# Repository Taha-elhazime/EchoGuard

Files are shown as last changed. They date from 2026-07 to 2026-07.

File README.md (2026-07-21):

# EchoGuard

EchoGuard is a security system that is meant to be more efficient than conventional cameras. The main part is a camera turret which is ceiling mounted and uses microphones in order to detect suspicious activity and lock on to it. It also uses a wall mounted ultrasonic sensor to detect anyone who walks past a certain line using bluetooth to transmit the data. Assembled demmo 
Demo video: demo

## What is included

This project includes the Cad files for the ultrasonic wall sensor and the turret demo as it is not ceiling mounted, along with the 3mf files in order to print them.
It also includes the codes to use the turret "main_v2.py" is the stable version which tracks the person's face using mediapipe, calculates the bearing of when the face was last seen and the offset from the center (dy and dx) and sends it to the arduino through serial communication. "main_v3" is an experimental version which does not work properly, where I tried to implement ROI in order to increase the speed at which mediapipe analyzed the images by reducing the load. The codes to upload to the microcontrollers are also included.
Before 3d printing the whole thing, I included 3mf files in order to test the snap fit of the ultrasonic sensor "snap_fit_test", along with "bearing_test" as the size of the bearings varies and the project uses bearings for the rotating base.
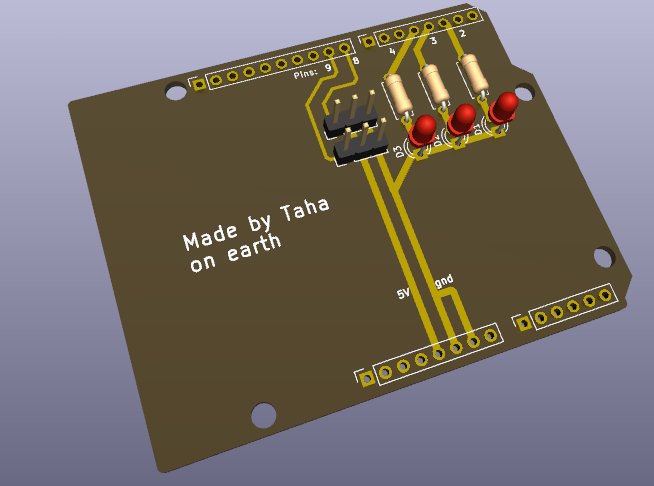
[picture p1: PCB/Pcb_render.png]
PCB
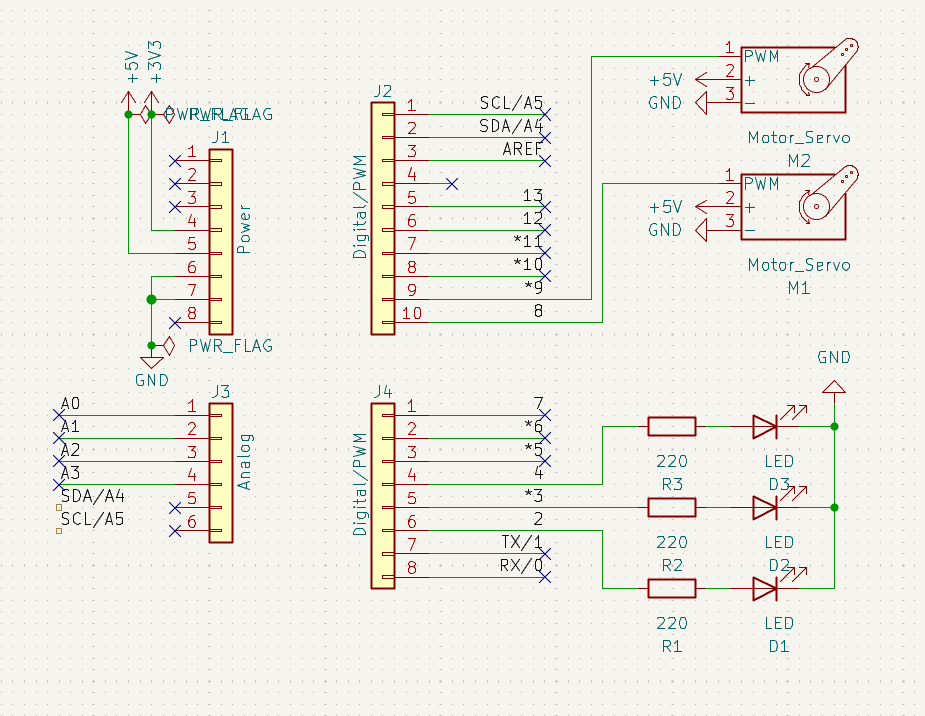
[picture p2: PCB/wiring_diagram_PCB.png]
Wiring_diagram
It also includes a simple pcb that would replace the breadboard and messy jumper wires  

## How to recreate the project

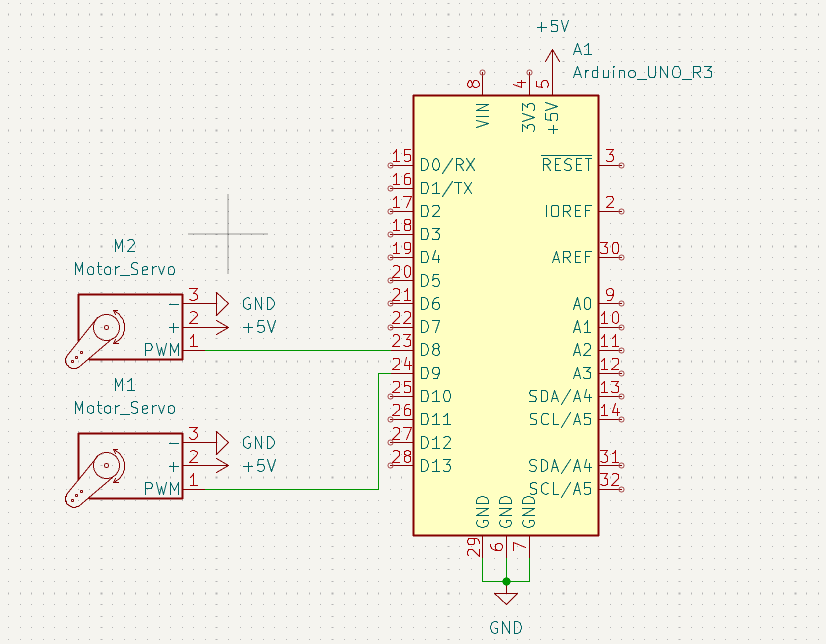
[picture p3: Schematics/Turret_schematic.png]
Turret schematic
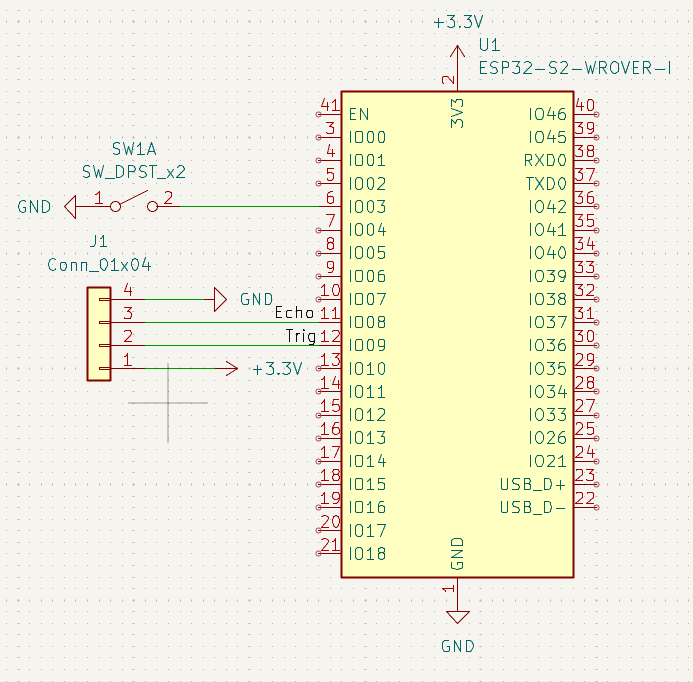
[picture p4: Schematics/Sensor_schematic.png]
Sensor schematic
The circuits are quite simple but here are schematics nontheless  

1. Use Arduino IDE in order to upload the code "EchoGaurd" for the arduino and note down the COM port used.

2. Use your code editor to update the port number in line the 8th line 
arduino = serial.Serial("COM3", 115200) change the number 3 with your port. 

3. Install the libraries mediapipe, opencv, pyserial, and numpy by running these comands in the terminal
```sh
pip install opencv-python
pip install mediapipe
pip install pyserial
pip install numpy
```

4. After 3d printing the parts, put the bearings in their holder, the bearing should have a diameter greater than the holder however try and make at least hald the bearing inside the holder.

5. Snap fit the servo at the base and either change the CAD file to fit your servo or use hot glue to connect it to the top part.

6. snap fit the tilt servo onto the top part and hot glue the camera holder and tape the camera (or adjust for a tight fit)

7. Ensure the servos are well oriented 

8. With the arduino IDE closed run the python script "main_v2" 
The demo should be up and running tracking your face, looking for it when out of frame, and returning to idle mode if it doesn't find you!

9. Hot glue a lazer if you want to see how dead accurate it is but be careful with your eyes!

10. In order to use the sensor simply snap fit the switch an solder the connections to your esp32, and close the box.

11. If you want the turret to look at the sensor when triggered use the "EchoGuard_sensor" version on your arduino and the python script "main_v2_sens"
In case of a "Port is busy" error simply close the python script
Also using the library manager install the following libraries:
Ultrasonic by Erick Simões
BluetoothSerial by Henry Abrahamsen

12. Update the sens_X and sens_Y angles to match the position of your sensor 

## Use pf AI
AI wasn't used in any major part of the project, ChatGpt was used to brainstorm and minor debugging in the python scripts. The CAD and PCB design along with the electronics and firmware were totally AI free.

## Tech Stack

### Software
- Python
- OpenCV
- MediaPipe
- Arduino IDE (C++)
- KiCad 
- Fusion 360
### Hardware
- Arduino Uno R4
- ESP32
- HC-SR04 Ultrasonic Sensor
- USB Webcam
- 2 pcs Servo Motors

## How it was made
The project started by designing the turret, the main issue was how I could make a rotating base that would be controlled with a servo. The issue was solved by using bearings. After testing the bearing holders I printed the base and the top parts.
The wiring was made using a breadboard before designing a pcb due to the connections breaking as the turret would rotate.
The software was then developed in Python using OpenCV and MediaPipe to detect the face offset from the center of the camera (dx and dy) along with the calculation of the bearing of when the face was last seen. Using trigonometry was necessery otherwise the camera would drift linearly to a corner.
A v3 version was made to optimize the code using ROI however it wasnt successful and I kept it for others to further improve it.

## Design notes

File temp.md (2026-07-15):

# EchoGuard
EchoGuard is a ceiling-mounted smart security device designed to protect a space more efficiently without needing multiple cameras. Using a dual microphone system to detect sounds and their direction using Time Difference of Arrival (TDOA). The device uses AI to idle search the room and to lock on to any suspicious activity using the dual microphone data.

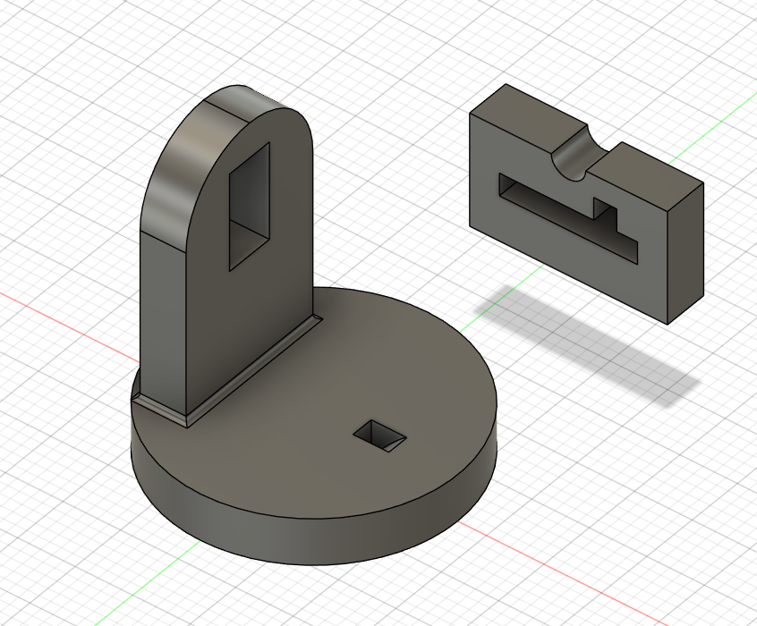
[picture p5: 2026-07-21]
CAD/Top_render.png

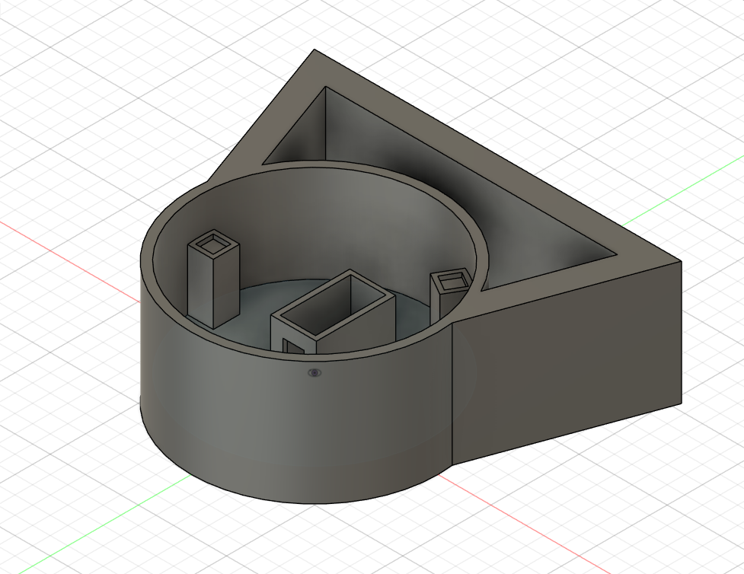
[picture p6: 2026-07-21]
CAD/Base_render.png

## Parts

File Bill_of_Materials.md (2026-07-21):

# Bill of Materials
The prices are sourced from amazon as that is where I sourced them myself.

## Amazon cart
Amazon Cart

## Turret:

1. 0.5kg eSUN PLA basic (any basic PLA should do the job): 16€ for 1kg

2. Arduino R4 Wifi (or any microcontroller that has a 5v output): 30€

3. Jumper cables and breadboard(in case the pcb is not used):  11€

4. 2pcs HAXIHA A097 Metal Gear Torque Digital Servo Motor (40mm by 19mm): 14€

5. Trust Oran web camera (1080p 30fps): 20€

6. 3pcs small bearings: 7€

## Sensor:

1. ELEGOO Esp 32 (any other board will do the job just check if it fits): 15€ for 2 pcs

2. ELEGOO ultrasonic sensor HC-SRO4: 10€ for 5 pcs

3. 1pcs GTIWUNG Rocker switch: 10€ for 35pcs

# Total cost
123€

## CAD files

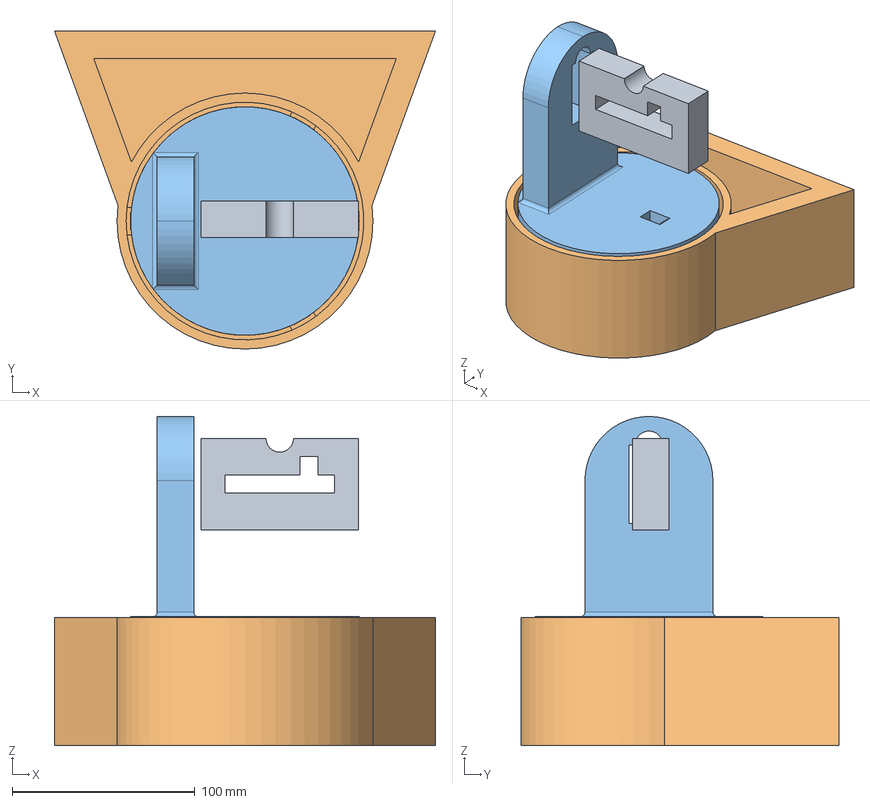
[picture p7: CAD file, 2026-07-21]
CAD/parts(stepFiles)/Assembled turret.step
208.4 x 174.0 x 180.0 mm

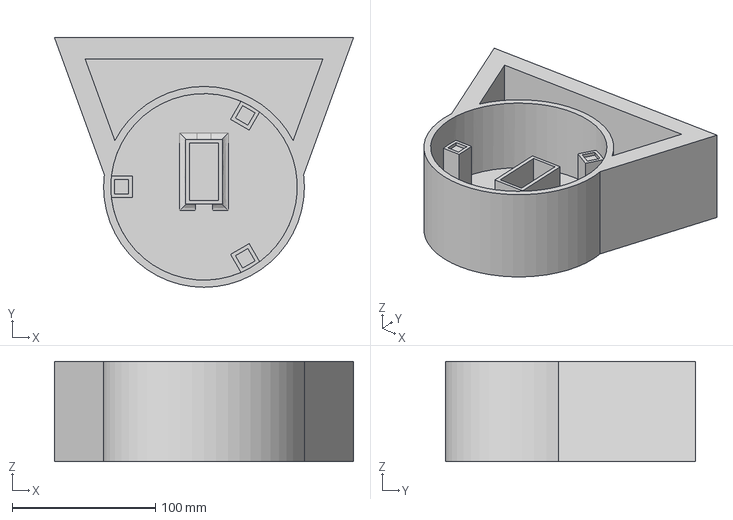
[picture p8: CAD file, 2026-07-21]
CAD/parts(stepFiles)/base.step
208.4 x 174.0 x 70.0 mm

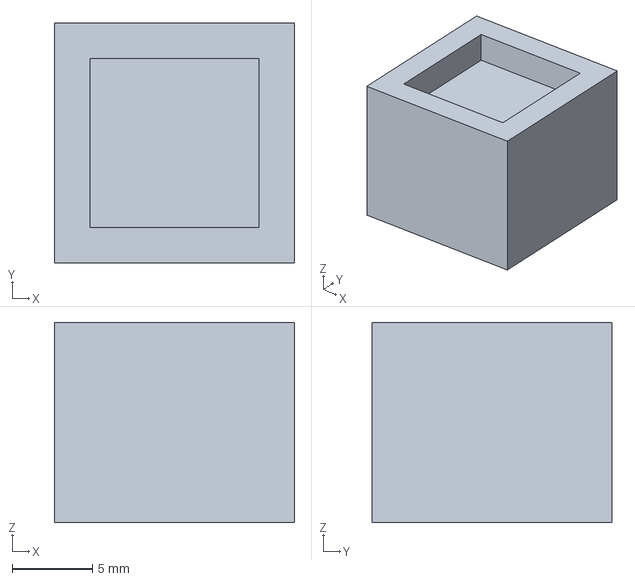
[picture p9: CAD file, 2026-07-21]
CAD/print/tests/bearing holder test.3mf
15.0 x 15.0 x 12.5 mm

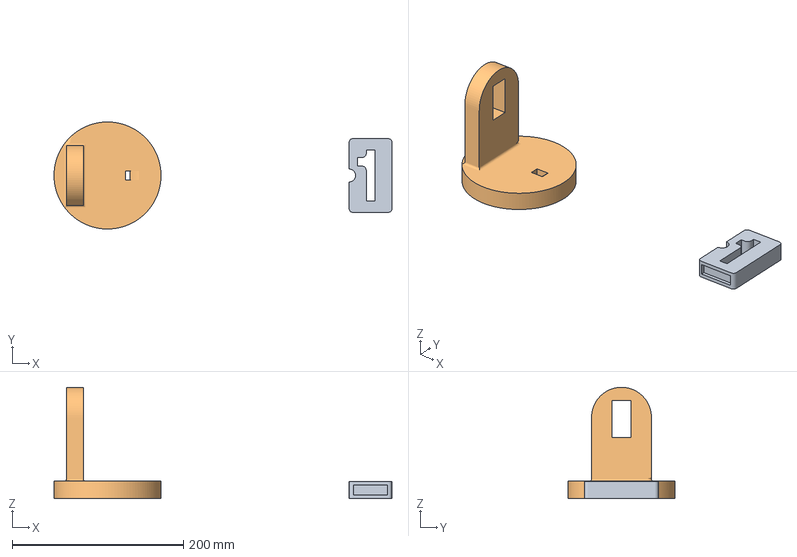
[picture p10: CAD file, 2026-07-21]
CAD/print/top_part+camera_mount.3mf
394.7 x 125.0 x 130.0 mm
Corpo1
Corpo2

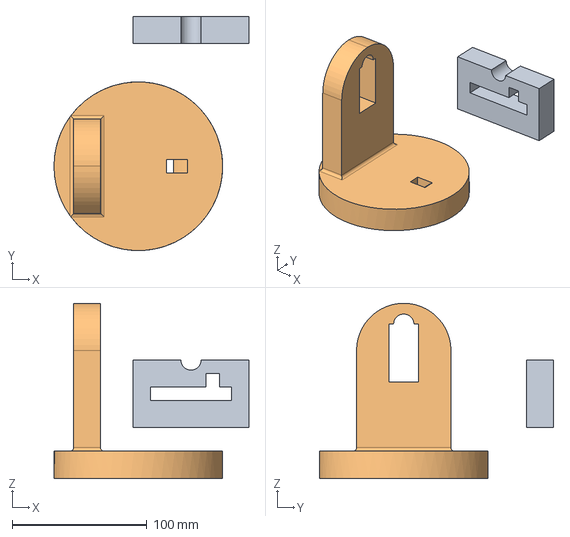
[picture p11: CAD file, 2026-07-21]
CAD/parts(stepFiles)/top_parts.step
144.5 x 173.5 x 130.0 mm

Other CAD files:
CAD/parts(f3d)/Assembled.f3z
CAD/parts(f3d)/base.f3d
CAD/parts(f3d)/top.f3d
CAD/parts(stlFiles)/Assembled_turret.stl
CAD/parts(stlFiles)/base.stl
CAD/parts(stlFiles)/top_parts.stl
CAD/print/base.3mf

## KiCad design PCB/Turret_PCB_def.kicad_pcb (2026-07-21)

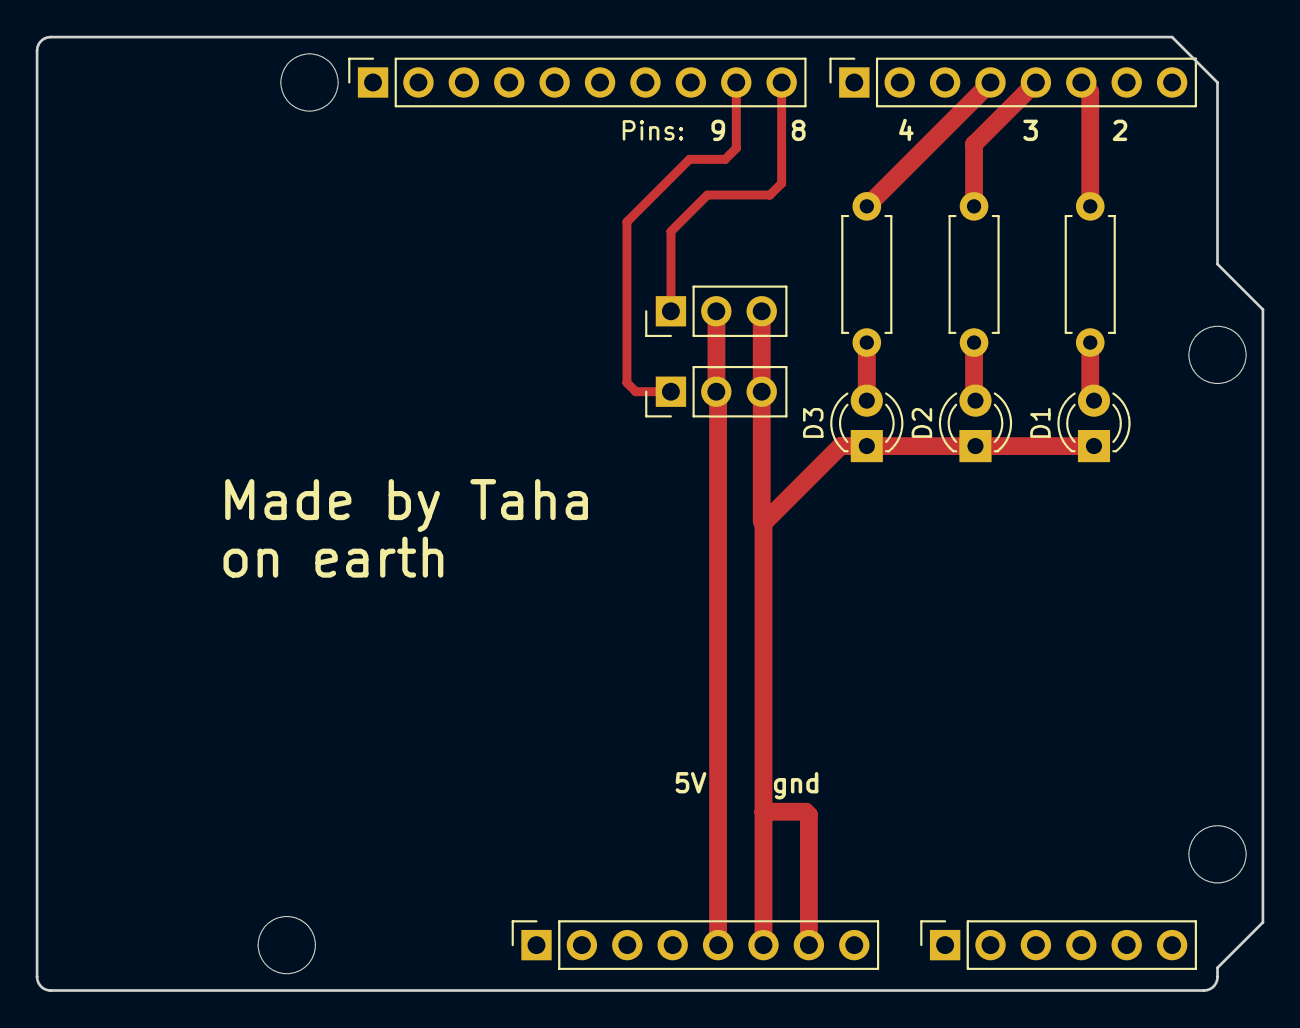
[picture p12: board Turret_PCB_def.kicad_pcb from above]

Board: 2 copper layers, 68.6 x 53.3 mm, 16 parts (0 on the bottom side), 10 nets.

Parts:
D1, D2, D3: LED; LED_D3.0mm
J1: Power; PinSocket_1x08_P2.54mm_Vertical
J2: Digital/PWM; PinSocket_1x10_P2.54mm_Vertical
J3: Analog; PinSocket_1x06_P2.54mm_Vertical
J4: Digital/PWM; PinSocket_1x08_P2.54mm_Vertical
M1, M2: Motor_Servo; PinHeader_1x03_P2.54mm_Vertical
MH1, MH2, MH3, MH4: MountingHole_3.2mm
R1, R2, R3: 220; R_Axial_DIN0207_L6.3mm_D2.5mm_P7.62mm_Horizontal

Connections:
+5V: J1.5, M1.2 (+), M2.2 (+)
/2: J4.6, R1.2
/4: J4.4, R3.2
/8: J2.10, M1.1 (PWM)
/*3: J4.5, R2.2
/*9: J2.9, M2.1 (PWM)
GND: D1.1 (K), D2.1 (K), D3.1 (K), J1.6, J1.7, M1.3 (-), M2.3 (-)
unnamed: D1.2 (A), R1.1
unnamed: D2.2 (A), R2.1
unnamed: D3.2 (A), R3.1

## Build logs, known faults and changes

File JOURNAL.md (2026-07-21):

title: EchoGuard
author: Taha kobbi El Hazime
description: Echoguard is a security system that is meant to be more effiecent than convencional cameras. The main part is a camera turret which is ceiling mounted and uses microphones in order to detect suspecious activity and lock on to it. It also uses an ultrasonic sensor that sticks to the wall and uses bluetooth to detect anyone who activates it. 
created_at: 2026-07-20

June 2nd to 7th
-printed the base 
-fixed the base and printed it again
-Caded the top part 
-printed and assembled it

June 8th and 9th
-researched and started coding the first version of EchoGuard
-Caded supports for microphone mounts

July 12th to 18th
-Did PCB design
-Caded the ultrasonic sensor
-Coded the firmware in arduino IDE
-started developing "main_v2"

July 19th to 21th 
-Tried developing ROI in v3
-Finishing touches to the 3d models
-Completed v2, added things such as tracking after the face is lost
-Made the sensor version of v2(the firmware and the python script)

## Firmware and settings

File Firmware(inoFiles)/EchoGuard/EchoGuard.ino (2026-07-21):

#include <Servo.h>

Servo Xservo;
Servo Yservo;
float k = 0.015;
float a = 3;
float Xangle = 90;
float Yangle = 90;
bool tracking = false;
int direction = 1;
unsigned long lostTime = 0;
int state = 2;
int idleCounter = 0;
int dirX = 1;
int dirY = 1;

void setup() {
Serial.begin(115200);
Xservo.attach(8);
Xservo.write(Xangle);
Yservo.attach(9);
Yservo.write(Yangle);
delay(1000);
} 

void loop() {

if (Serial.available()){ 
String msg = Serial.readStringUntil('\n');

int firstComma = msg.indexOf(',');
int secondComma = msg.indexOf(',', firstComma + 1);
int thirdComma = msg.indexOf(',', secondComma +1);

int dx = msg.substring(0, firstComma).toInt();
int dy = msg.substring(firstComma + 1, secondComma).toInt();
tracking = msg.substring(secondComma + 1).toInt();
int bearing = msg.substring(thirdComma + 1).toInt();


if(tracking){
state = 0;
Xangle += dx * k;
Yangle += dy *k;

Xangle = constrain(Xangle, 0, 180);
Yangle = constrain(Yangle, 35, 180);

Xservo.write(Xangle);
Yservo.write(Yangle);
}else if(state == 0){
state = 1;
lostTime = millis();

Xangle = Xangle;
Yangle = Yangle;

Xangle += dx * a;
Yangle += dy * a;

Xangle = constrain(Xangle, 0, 180);
Yangle = constrain(Yangle, 35, 180);

Xservo.write(Xangle);
Yservo.write(Yangle);

}else if(state == 1){
 if(millis() - lostTime < 500){

float angleRad = radians(bearing-90);
float stepSize = 5;

Yangle -= sin(angleRad)*a;
Xangle += cos(angleRad)*a;

Xangle = constrain(Xangle, 0, 180);
Yangle = constrain(Yangle, 30, 180);

Xservo.write(Xangle);
Yservo.write(Yangle);
}else {
  state = 2;
}
} else if(state == 2){
  idleCounter++ ;
  if(idleCounter >= 8){
    idleCounter = 0;
    Xangle += dirX * 3;

    if(Xangle > 180){
      dirX = -1;
    }
    if(Xangle < 0) {
      dirX = 1;
  }

  Yangle += dirY * 3;
  if (Yangle >= 150){
    dirY = -1;
  }
  if(Yangle <= 35){
    dirY = 1;
  }


  
}

Xangle = constrain(Xangle, 0, 180);
Yangle = constrain(Yangle, 35, 180);

Xservo.write(Xangle);
Yservo.write(Yangle);

}

}
}

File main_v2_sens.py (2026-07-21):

import cv2 
import numpy as np
import time
import mediapipe as mp
import math
import serial

arduino = serial.Serial("COM3", 115200)
esp = serial.Serial("COM7", 115200)
time.sleep(2)

mode = 0
prKey = -1

position1X = 0
position1Y = 0
position2X = 0
position2Y = 0

round = 0
speed = 0

x = 1
y = 1
center_x = 2
center_y = 2
width = 1
height = 1
face_h = 1
face_w = 1
red = 1

sensor = 0

camera = cv2.VideoCapture(0)
cv2.VideoCapture("video.mp4")

mp_face_detection = mp.solutions.face_detection

detector = mp_face_detection.FaceDetection(
    model_selection=0,
    min_detection_confidence=0.5
)

print (str(camera.isOpened()))

if camera.read():
    print("Success")
else:
    print("nope")

while True:

    success, frame = camera.read()
    height, width, channels = frame.shape
    rgb_frame = cv2.cvtColor(frame, cv2.COLOR_BGR2RGB)

    results = detector.process(rgb_frame)
    tracking = results.detections is not None

   
    
    blue = speed // 5.8

    if results.detections:
        for detection in results.detections:

            bbox = detection.location_data.relative_bounding_box



            x = int(bbox.xmin * width)
            y = int(bbox.ymin * height)
            face_w = int(bbox.width * width)
            face_h = int(bbox.height * height)

            center_x = x + face_w // 2
            center_y = y + face_h // 2

        #Speed

            round = round + 1

            if round == 6:
                position1X = x 
                position1Y = y
            
            if round == 16:
                position2X = x
                position2Y = y
                round = 0

                speed = 10*(math.sqrt((position1X - position2X)**2 + (position1Y - position2Y)**2))


            cv2.rectangle(
                frame,
                (x, y),
                (x + face_w, y + face_h),
                (red, 0, 0),
                2
            )

            cv2.circle(
                frame,
                (center_x, center_y),
                5,
                (0, 255, 0),
                -1
            )

            cv2.line(
                frame,
                (width // 2, height // 2 ),
                (center_x, center_y),
                (0, 255, 0),
                1
            )


    #Area ratio

    area = height * width

    areaF = face_h * face_w

    areaR = areaF / area
    
    #print("ratio: " + str(areaR))

    #-------------------------------------------------------------------

    dy = -(center_y - (height // 2))

    dx = -(center_x - (width // 2))


    

    angle = math.degrees(math.atan2(dy, dx))
    bearing = (90 - angle) % 360
    #print(str(bearing)) 

    if esp.in_waiting:
        sensor = int(esp.readline().decode().strip())

    if tracking:
        arduino.write(f"{dx},{dy},{int(tracking)},0,{sensor}\n".encode())
    else:
        arduino.write(f"0,0,{int(tracking)},{int(bearing)},{sensor}\n".encode())

    print(bearing)



    cv2.imshow("camera", frame)

    key = cv2.waitKey(1)

    if key == ord("q"):
        break

camera.release()

cv2.destroyAllWindows() 

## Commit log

2026-07-21 Project upload
    [Assembled turret.step, Assembled.f3z, Assembled_turret.stl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]
2026-07-21 1st rejection: BMO list, PCB
    [Turret_PCB_def.kicad_pcb]
